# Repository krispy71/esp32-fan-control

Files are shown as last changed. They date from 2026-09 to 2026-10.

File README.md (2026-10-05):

# esp32-fan-control

Smart temperature and airflow controller for charcoal and wood-based smokers built on the ESP32 microcontroller.

## Overview

The controller continuously reads temperature sensors in the smoke chamber and meat, orchestrating both a **5V forced-air blower fan** and a **servo-controlled mechanical damper** (inspired by the **HeaterMeter** and **Roto-Damper** / **MicroDamper** open-hardware projects).

### Key Features

* **Dual-Actuator Airflow Management**:
  * **Servo-Controlled Damper**: Prevents the convective "chimney draft effect" when the pit reaches target temperature, and provides fine-tuned natural draft regulation at low-and-slow cooking temperatures ($225^\circ\text{F}$).
  * **5V Radial Blower Fan**: Kicks in automatically above a configurable airflow threshold to deliver forced air during warm-up, setpoint recovery, or high-heat cooks.
  * **RJ45 Interface**: Uses the 8P8C pin assignments (Pins 3: +5V, 4: GND, 5: +5V Fan, 6: Servo Signal) with 5V damper/fan hardware. This project's USB power rail is 5V.
* **Multi-Probe Temperature Acquisition**:
  * Supports one K-type pit probe through a MAX31855K by default, or a MAX31856 K-type build; a second wired food converter is optional.
  * Supports wireless temperature probes (e.g. MEATER / BLE beacons) behind a pluggable sensor interface.
* **Autonomous Safety & Fail-Safes**:
  * All closed-loop regulation and safety logic reside strictly on the ESP32.
  * **Lid-Open Detection**: Detects rapid negative $\Delta T$ and automatically halts the fan and closes the damper to prevent firebox flare-ups.
  * **Fail-Safe Shutdown**: Automatically closes damper and stops fan on sensor disconnect.
* **Local Web Control Interface**:
  * Reachable over local Wi-Fi using provisioned HTTPS access to monitor graphs, adjust setpoints, and tune PID/servo calibration parameters without requiring cloud services.

## Documentation

* [Project North Star](docs/north-star.md) — System requirements, behavior, and acceptance criteria.
* [System Architecture & Engineering Specification](docs/system-architecture.md) — Electrical schematic, pinout, circuit design, and modulation curves.
* [PocketSWE Agent Contract](AGENTS.md) — Onion architecture invariants and dependency rules.
* [Firmware setup and testing](firmware/README.md) — Converter selection, build commands, and physical bench checklist.
* [Private device access](docs/device-access.md) — Per-device credentials, certificates, and simulator setup.
* [Review verification](docs/review-verification.md) — Software evidence and remaining physical qualification.

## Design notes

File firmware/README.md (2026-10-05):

# ESP32 Smoker Controller Firmware & Web Interface

Embedded C++17 firmware and offline-first web dashboard for the ESP32 Smoker Fan & Servo Damper Controller, structured using the PocketSWE Onion Architecture.

---

## 1. Directory Structure

```text
firmware/
├── platformio.ini              # PlatformIO build configuration (esp32dev / esp32dev-max31856 / native)
├── partitions.csv              # Custom 4MB partition table (2.5MB App + 1.44MB LittleFS)
├── include/                    # Common project headers
├── data/                       # LittleFS web dashboard static assets
│   ├── index.html              # Responsive pitmaster control dashboard
│   ├── style.css               # Dark theme responsive mobile-first stylesheet
│   └── app.js                  # Authenticated polling telemetry client & HTML5 canvas trend graph
├── src/
│   ├── Domain/                 # Pure domain business logic (zero Arduino/ESP32 dependencies)
│   │   ├── Temperature.hpp     # TemperatureReading, SensorRole, SensorFault
│   │   ├── Airflow.hpp         # AirflowDemand, ActuatorTargets, ActuatorCoordinator
│   │   ├── Configuration.hpp   # SmokerConfig domain model and validation invariants
│   │   ├── PID.hpp             # Discrete PID regulator with anti-windup clamping
│   │   ├── LidDetector.hpp     # Lid-open suppression state machine
│   │   └── BLEDecoder.hpp      # Passive advertisement packet decoders (MEATER, Inkbird)
│   ├── Services/               # Core application orchestration
│   │   ├── Ports/              # Abstract hardware contracts
│   │   │   ├── TemperatureSensorPort.hpp
│   │   │   ├── DamperActuatorPort.hpp
│   │   │   ├── BlowerActuatorPort.hpp
│   │   │   ├── ConfigStoragePort.hpp
│   │   │   └── TelemetryPort.hpp
│   │   └── SmokerControlService.hpp
│   ├── Adapters/               # Concrete hardware, network, and storage drivers
│   │   ├── Actuators/
│   │   │   ├── ESP32ServoDamperAdapter.hpp # 50Hz LEDC PWM with idle-detach
│   │   │   └── ESP32PWMBlowerAdapter.hpp   # 25kHz ultrasonic MOSFET PWM
│   │   ├── Sensors/
│   │   │   ├── MAX31855SensorAdapter.hpp   # SPI thermocouple acquisition & fault decoding
│   │   │   ├── BLEProbeAdapter.hpp         # BLE passive scanner for meat probes
│   │   │   └── CompositeSensorAdapter.hpp  # Wireless primary with wired thermocouple fallback
│   │   ├── Telemetry/
│   │   │   └── SerialTelemetryAdapter.hpp  # Console/serial output formatter
│   │   ├── Storage/
│   │   │   └── ESP32NVSConfigAdapter.hpp   # Non-Volatile Storage (NVS) Preferences adapter
│   │   └── Network/
│   │       └── WebServerAdapter.hpp        # HTTPS REST endpoints & LittleFS allowlist
│   └── Controller/
│       └── main.cpp            # FreeRTOS task setup & pin bootstrap
└── test/
    └── test_domain.cpp         # Host-executable C++17 unit tests
```

---

## 2. Hardware Pinout Reference

> For complete point-to-point breadboard wiring and schematics, refer to [docs/wiring-diagram.md](../docs/wiring-diagram.md).

| Function | ESP32 GPIO | Peripheral / Mode | Notes |
| :--- | :---: | :--- | :--- |
| **Blower Fan Gate** | `GPIO 25` | LEDC Ch 0, 25 kHz PWM | Drives gate of N-MOSFET (AO3400A / IRLZ44N) |
| **Servo Damper Signal** | `GPIO 26` | LEDC Ch 2, 50 Hz PWM | Connects to RJ45 Pin 6 (MG90S micro-servo) |
| **SPI SCK** | `GPIO 18` | Hardware SPI Clock | Shared clock line for MAX31855 amplifiers |
| **SPI MISO** | `GPIO 19` | Hardware SPI Data | Shared serial data in from MAX31855 |
| **CS Pit Thermocouple** | `GPIO 5` | Active-low Chip Select | Dedicated CS for pit/chamber probe |
| **SPI MOSI** | `GPIO 23` | Hardware SPI Data | Required for display and MAX31856 |
| **CS Food Thermocouple** | `GPIO 21` | Active-low Chip Select | Optional; disabled unless `SMOKER_FOOD_CS=21` |

---

## 3. Web Dashboard & REST API Endpoints

The web dashboard is served over HTTPS from ESP32 LittleFS using a per-device SoftAP and administrator credential. Provision the private access files using [docs/device-access.md](../docs/device-access.md). Unprovisioned firmware keeps web access disabled while wired control remains autonomous.

### HTTP Endpoints

| Method | Endpoint | Description |
| :--- | :--- | :--- |
| `GET` | `/` | Serves dashboard HTML (`index.html`) |
| `GET` | `/style.css` | Serves dark theme CSS |
| `GET` | `/app.js` | Serves real-time JavaScript frontend |
| `GET` | `/api/telemetry` | Returns instantaneous JSON state snapshot |
| `GET` | `/api/command?id=...` | Poll queued/applied/rejected command and persistence result |
| `GET` | `/api/config` | Read active tuning, calibration, and configuration version; cloud token redacted |
| `POST` | `/api/setpoint` | Update pit setpoint: `{"setpoint": 225.0, "config_version": 0}` |
| `POST` | `/api/config` | Update tuning parameters and persist to NVS flash |
| `POST` | `/api/lid-pause` | `{"action":"pause","config_version":0}` or `"resume"` |

All routes require administrator authentication over TLS. The dashboard polls telemetry
at 1 Hz. Each POST requires the current `config_version` returned by `/api/config`;
stale versions return 409. A 202 response contains a `request_id`, indicating queued
acceptance. Poll `/api/command?id=...` until applied/rejected and check `persistence`:
`saved`, `failed`, `unchanged`, or `not_configured`. An applied setting can still fail to
persist; the dashboard reports this separately. A pending command prevents a second
submission until its result is collected. The last eight results are retained in RAM.

`POST /api/config` accepts tuning and calibration fields, including
`servo_min_pulse_us`, `servo_max_pulse_us`, and `servo_inverted`. Omit
`meater_cloud_token` to preserve it; send an empty string to remove it. API responses
expose only whether it is configured.

### Example Telemetry JSON Payload

```json
{
  "timestamp_ms": 142300,
  "pit_temp_f": 224.8,
  "meat_temp_f": 165.2,
  "setpoint_f": 225.0,
  "damper_position_pct": 42.0,
  "blower_speed_pct": 0.0,
  "demand_pct": 17.0,
  "is_pit_valid": true,
  "is_meat_valid": true,
  "lid_open": false,
  "status": "REGULATING",
  "is_meat_wireless": true,
  "meat_battery_pct": 92,
  "meat_probe_name": "MEATER+"
}
```

---

## 4. FreeRTOS Task Architecture

* **Core 1 — Control task (`SmokerControl`)**, priority 2: owns the control service,
  actuator state, and wired sensor sampling. It runs PID and normal telemetry at a nominal 1 Hz, checks pit safety between
  those cycles, and services converter/servo upkeep every 20 ms. Hardware transactions and task scheduling add
  latency; physical timing must be measured on the bench.
* **Core 0 — Network task (`SmokerNetwork`) and HTTPS server**: updates BLE/cloud
  caches, serves the dashboard, and renders the display. Web requests submit typed
  commands through a bounded queue and read copied state; they never mutate the
  control service directly. Wireless cache exchanges use short locks.

The pinned Arduino 2.0.17 BLE client has service-discovery ownership defects.
`tools/patch_ble_client.py` uses a [PlatformIO build middleware](https://docs.platformio.org/en/latest/scripting/middlewares.html)
to compile a repaired copy under `.pio/build/<environment>/patched_ble`:
duplicate service UUID instances are discarded before allocation, and rediscovery
clears the secondary service index. The shared framework installation is unchanged.
An unexpected source checksum stops the build so framework upgrades require an
explicit patch review. `test/test_ble_sdk_patch.py` executes the emitted vendor
discovery and cleanup bodies across repeated duplicate-instance discoveries.
* **Shared SPI**: an explicit bus owner serializes complete display/converter frames,
  including transaction settings and chip-select lifetime. The display uses MOSI23.
* **Startup**: application ownership is constructed inside `setup()`. The blower is
  stopped, saved configuration is loaded, calibrated closure is commanded, and then
  tasks start. LEDC fan channel 0 and servo channel 2 use independent timers.

---

## 5. Building, Testing, and Simulation

### Repeatable software verification

From the repository root, install `uv`, a C++17 compiler, OpenSSL, Node/npm (for browser accessibility checks), and the runtime
libraries `libcjson.so.1` and `libmbedcrypto.so.7`. Build an ESP32 environment once to
install its framework headers, then run:

```bash
uv run --no-project --with platformio pio run -d firmware -e esp32dev
uv run --no-project --with playwright==1.58.0 python -m playwright install chromium
tools/verify.sh --firmware --browser
```

The driver runs Python tests, strict C++ domain/service/native checks, production
Arduino paths against SPI/PWM/NVS spies, the firmware HTTPS handler, both ESP32
converter builds, and the real simulator/browser flow. Omit `--firmware` or
`--browser` to skip those optional stages. Hardware spies do not establish electrical
accuracy or actual servo movement.

### Running Local Python Web Simulation
Launch the desktop simulator with the live web dashboard served at `https://127.0.0.1:8443`:

```bash
uv run python -m esp32_fan_control.Controller.cli --web --access-dir "$HOME/.local/share/esp32-smoker/device-a"
```

### Compiling Firmware for ESP32 Target
Using PlatformIO Core via `uv`:

```bash
cd firmware
uv run --with platformio pio run -e esp32dev
```

The default `esp32dev` environment supports one wired **K-type probe through a
MAX31855K** on CS5. For a MAX31856 configured as K-type, build
`-e esp32dev-max31856` and connect MOSI23 as well. A second wired food converter is
optional: add `-D SMOKER_FOOD_CS=21` to that environment's build flags when installed.
Both converters share SCK18/MISO19 and have separate CS pins. Never connect a bare
thermocouple directly to an ESP32 analog input.

### Flashing Firmware & LittleFS Web Assets to ESP32

First provision and copy the three private device files described in
[device access](../docs/device-access.md). Substitute the MAX31856 environment in
both upload commands when using that converter.
```bash
cd firmware

# 1. Upload program binary (compiled against custom 2.5MB app partition)
uv run --with platformio pio run -e esp32dev -t upload

# 2. Upload web dashboard files from firmware/data/ to LittleFS partition (1.44MB)
uv run --with platformio pio run -e esp32dev -t uploadfs

# 3. Open interactive serial console with automatic exception decoder
uv run --with platformio pio device monitor -b 115200
```

---

## 6. Hardware Flashing & Pre-Flight Verification Checklist

Before connecting high-draw actuators or attaching the unit to your smoker, complete this pre-flight verification sequence on the bench.

### 6.1 Pre-Power Multimeter & Pin Sanity Check

Perform these checks with the ESP32 **unpowered**:

- [ ] **Power Rail Isolation**: Check resistance between the 5V rail and GND using a multimeter. Ensure no short circuit exists ($R > 10\,\text{k}\Omega$).
- [ ] **Logic Level Isolation (3.3V vs 5V)**:
  - Verify MAX31855 VCC is wired strictly to ESP32 `3V3` (3.3V LDO pin), **never** to 5V.
  - Verify Blower Fan (+) and Servo (+) are connected to the 5V USB rail.
- [ ] **Flyback Diode Orientation**: Ensure the 1N5819 diode is placed directly across the fan terminals with the **cathode (silver band)** connected to +5V and **anode** connected to the MOSFET Drain (Fan -).
- [ ] **Gate Pull-Down**: Verify the $100\,\text{k}\Omega$ resistor is connected between `GPIO 25` (MOSFET Gate) and `GND`. This guarantees the blower fan remains completely off when the ESP32 is booting or in reset.
- [ ] **Brownout Buffer Capacitor**: Confirm the $1000\,\mu\text{F}$ electrolytic capacitor across the 5V bus is installed with correct polarity (negative stripe to GND).

### 6.2 Flashing & Initial Boot Verification

1. Connect the ESP32 DevKit to your computer via USB.
2. Flash the firmware binary and LittleFS filesystem:
   ```bash
   cd firmware
   uv run --with platformio pio run -e esp32dev -t upload
   uv run --with platformio pio run -e esp32dev -t uploadfs
   ```
3. Open the serial terminal:
   ```bash
   uv run --with platformio pio device monitor -b 115200
   ```
4. Verify startup behavior:
   - [ ] Fan remains off until a valid pit sample is available; servo closes at boot.
   - [ ] With provisioned access files, serial reports
     `[Web] Provisioned HTTPS dashboard ready on port 443.`
   - [ ] The private per-device SSID becomes visible; no password is printed.
   - [ ] No shared-bus or control-task initialization error is reported.
   - [ ] Periodic telemetry shows pit validity, demand, damper, fan, and lid status.

### 6.3 Functional Bench Calibration & Verification

Step through each subsystem to confirm physical hardware operation:

#### A. Thermocouple Subsystem (MAX31855K or MAX31856)
- [ ] **Ambient Sanity**: With thermocouple attached, verify serial console reports room temperature (~68°F – 74°F).
- [ ] **Thermal Response**: Pinch the tip of the thermocouple between your fingers; confirm temperature immediately rises to 80°F–88°F.
- [ ] **Open-Circuit Fault Detection**: Unplug or disconnect one thermocouple lead. Verify the serial log reports a pit fault and demand drops to `0.0%` (failsafe lock).

#### B. Damper Actuator Subsystem (MG90S Servo)
- [ ] **Zero-Position (Closed)**: At initial boot, confirm the damper rotor moves to fully closed position ($0^\circ$).
- [ ] **Idle-Detach Verification**: Observe the servo after it reaches position. Within 1.5 seconds, the ESP32 automatically detaches the PWM pin (`ledcDetachPin`). Confirm all servo hum, vibration, and jitter stops completely.
- [ ] **Full Range Sweep**: Adjust calibration in the dashboard and verify closed/open mechanical endpoints and direction. Confirm values persist across a reboot; verify movement is followed by idle detach.

#### C. Blower Fan Subsystem (N-MOSFET & 25kHz PWM)
- [ ] **Low-Demand Deadband**: When demand is below the airflow threshold (default $\le 40\%$), confirm the blower fan is completely idle (0% duty cycle) while the damper modulates airflow.
- [ ] **High-Demand Activation**: When demand exceeds the configured threshold (default 40%), confirm the blower fan spins up smoothly without any audible coil whine (verified 25 kHz ultrasonic PWM).
- [ ] **Max Speed (100% Demand)**: At 100% demand, confirm the fan runs at full 5V velocity.

#### D. Web Dashboard & Wi-Fi Connectivity
- [ ] Connect to the per-device Wi-Fi network listed in your private `operator-access.txt`.
- [ ] Open a browser and navigate to `https://192.168.4.1`.
- [ ] Verify the responsive pitmaster dashboard loads with real-time temperature gauges and canvas graph.
- [ ] Tap the **Setpoint** control, enter `250`, and submit. Verify:
  - Web UI displays new setpoint.
  - Dashboard reports application and successful persistence.
  - The value persists after power-cycling the ESP32 (stored in NVS flash).
- [ ] Tap **Lid Open Pause**. Verify status changes to `LID_OPEN`, blower turns off, and damper closes. Use the resume control to cancel.

#### E. Wireless BLE Meat Probe Verification (Optional / If Equipped)
- [ ] Turn on a compatible BLE meat probe (MEATER, Inkbird, or BBQ-BT).
- [ ] Within 10–30 seconds, confirm the serial log and web dashboard update the meat channel from `N/C` to the live wireless temperature reading with probe name and battery status (e.g. `Meat: 135.2 F [MEATER+ 95%]`).
- [ ] If a wired thermocouple is also plugged into the Food 1 channel, remove the wireless probe or move it out of range; verify the controller cleanly falls back to the wired probe reading without interrupting the pit regulation loop.

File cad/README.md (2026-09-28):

# Parametric Fan & Servo Damper CAD

This directory contains the 3D-printable mechanical CAD design for the ESP32 Smoker Controller, implemented in OpenSCAD.

> **Mechanical Guides**:
> - **Design 1 (Integrated Barrel Damper Pod)**: See [docs/assembly-guide.md](../docs/assembly-guide.md) and [docs/3d-printed-parts-guide.md](../docs/3d-printed-parts-guide.md).
> - **Design 2 (Roto-Damper RD3 Rotary Puck)**: See [docs/roto-damper-guide.md](../docs/roto-damper-guide.md).

| Design 1: Integrated Barrel Damper Pod | Design 2: Roto-Damper RD3 Rotary Puck |
| :---: | :---: |
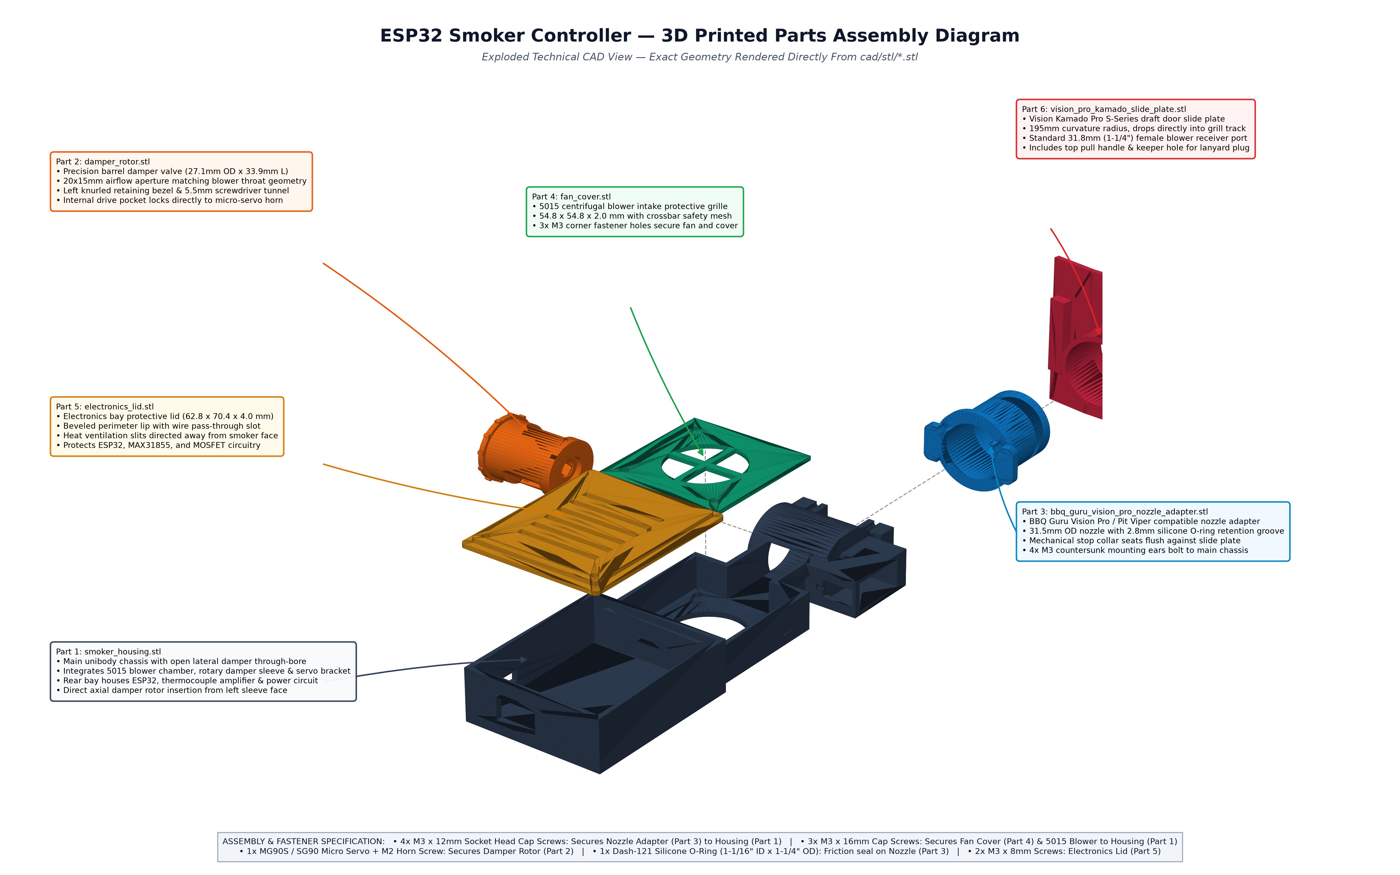
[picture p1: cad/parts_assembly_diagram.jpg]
Design 1 Exploded Diagram
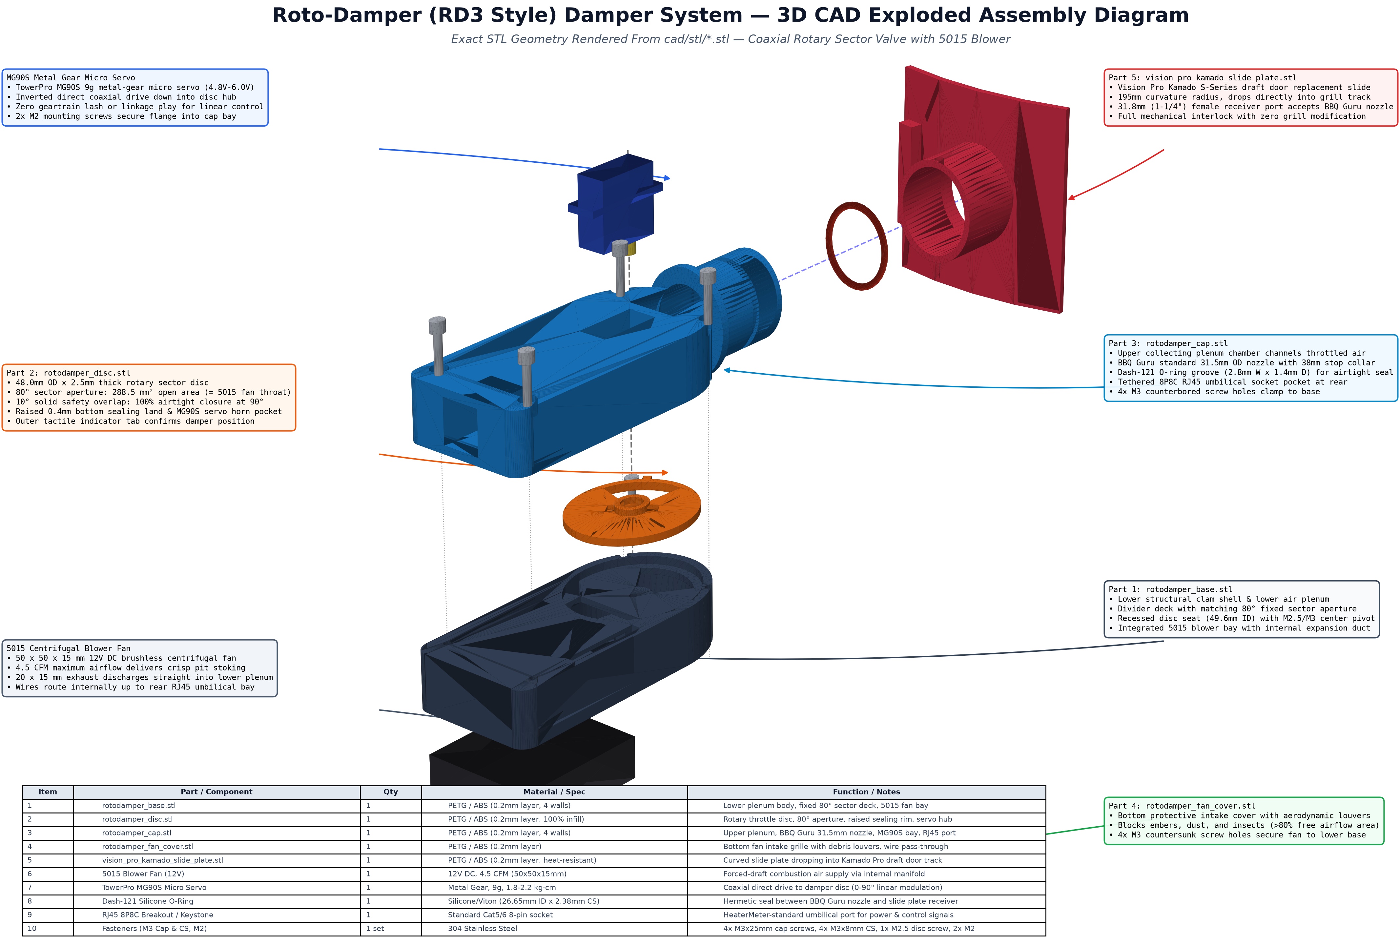
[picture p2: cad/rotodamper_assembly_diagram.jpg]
Design 2 Exploded Diagram
|  |  |

---

## Design Highlights

1. **Parametric Output Adapter**:
   - **BBQ Guru Vision Pro / Pit Viper Preset** (`output_preset = "bbq_guru"`):
     - Sized specifically to fit into the BBQ Guru metal Vision Pro S-Series adapter sleeve (`https://www.bbqguru.com/product/vision-pro-adapter-s-series/`).
     - Outer diameter: **31.5mm** (standard 1-1/4" nominal with 0.25mm slip-fit clearance).
     - Insertion length: **32.0mm** with 1.5mm lead-in chamfer.
     - Integrated O-ring retention groove (2.8mm wide, 1.4mm deep, located 10mm from tip) for airtight friction sealing with standard Dash-121 / Dash-122 silicone O-rings.
     - Integrated 38mm mechanical stop collar to prevent over-insertion against the adapter face.
   - **Vision Pro S-Series Curved Slide Door Replacement** (`part = "vision_pro_plate"`):
     - Complete 3D-printable curved slide door that drops directly into the Vision Kamado Pro S-Series bottom vent track (width: 82mm, height: 74mm, radius: 195mm).
     - Features a female 31.8mm BBQ Guru receiver port and pull handle tab.
   - **Round Pipe**: Configurable outer diameter (e.g., 25.4mm for 1" NPT, 31.75mm for 1.25", or 38.1mm for 1.5").
   - **Rectangular Duct**: Configurable width and height to match Kamado bottom slide vents (Big Green Egg, Kamado Joe) or Weber Smokey Mountain (WSM) draft dampers.
   - **Mounting Flange**: Optional bolt-on flange with configurable screw spacing.
   - **Modular Attachment**: The output nozzle attaches via 4x M3 screws, allowing you to swap smoker adapters without reprinting the main housing.

2. **Parametric Fan Sizing**:
   - `fan_size` & `fan_depth` accommodate standard radial blower sizes:
     - **5015** (`fan_size = 50`, `fan_depth = 15`): Ultra-compact for small/medium cookers (WSM 18.5", Kamado Classic).
     - **7530** (`fan_size = 75`, `fan_depth = 30`): High-output for drum smokers and larger pits.
     - **9733** (`fan_size = 97`, `fan_depth = 33`): Heavy-duty commercial/offset airflow.

3. **Two System Packaging Configurations**:
   - **Configuration A: All-in-One Integrated Pod (`include_electronics_bay = true`)**:
     - Contains an attached electronics bay housing the ESP32 development board, 5V USB-C power breakout, MOSFET blower switch, and MAX31855 thermocouple amplifier.
     - Direct USB-C power connection for phone chargers and USB battery bricks.
   - **Configuration B: Slim Tethered Pod (`include_electronics_bay = false`)**:
     - Eliminates the electronics bay in favor of an RJ45 modular jack recess.
     - Connects via standard Cat5/Cat6 umbilical cable to a remote controller base unit.

4. **Servo-Driven Damper Valve**:
   - Houses a TowerPro MG90S metal-gear (or SG90) micro-servo.
   - The cylindrical barrel rotor features a cross-bore aperture that aligns with the fan exhaust at 90° rotation and hermetically blocks the airway at 0° to prevent the chimney draft effect.

---

## Printable Parts in `smoker_damper.scad`

Select which component to render via the `part` variable or from the command line:

```bash
# 1. Main Housing Body (holds fan, damper, and servo)
openscad -o housing.stl -D 'part="housing"' smoker_damper.scad

# 2. Damper Rotor (rotating valve cylinder)
openscad -o rotor.stl -D 'part="rotor"' smoker_damper.scad

# 3. Output Adapter - BBQ Guru Vision Pro / Pit Viper Nozzle (1.25" / 31.5mm OD with O-ring groove)
openscad -o adapter_bbq_guru.stl -D 'part="output_adapter"; output_preset="bbq_guru"' smoker_damper.scad

# 4. Vision Pro S-Series Curved Slide Door Replacement Plate (drops into Kamado track)
openscad -o vision_pro_plate.stl -D 'part="vision_pro_plate"' smoker_damper.scad

# 5. Output Adapter - Round Pipe (1" NPT)
openscad -o adapter_round.stl -D 'part="output_adapter"; output_preset="npt_1"' smoker_damper.scad

# 6. Output Adapter - Rectangular (50mm x 30mm)
openscad -o adapter_rect.stl -D 'part="output_adapter"; output_preset="kamado_rect"' smoker_damper.scad

# 7. Electronics Bay Lid (for Config A)
openscad -o lid.stl -D 'part="lid"' smoker_damper.scad

# 8. Fan Intake Protective Grille
openscad -o fan_cover.stl -D 'part="fan_cover"' smoker_damper.scad
```

---

## Printable Parts in `roto_damper.scad` (Design 2: Roto-Damper)

Compile the modular 4-piece Roto-Damper puck:

```bash
# 1. Base Housing (lower shell, 5015 fan bay, static lower plenum, sector deck)
openscad -o rotodamper_base.stl -D 'part="base"' roto_damper.scad

# 2. Rotary Damper Disc (80-degree sector aperture, low-friction rim, servo hub)
openscad -o rotodamper_disc.stl -D 'part="disc"' roto_damper.scad

# 3. Cap Housing (upper plenum, 31.5mm BBQ Guru nozzle, MG90S bay, RJ45 port)
openscad -o rotodamper_cap.stl -D 'part="cap"' roto_damper.scad

# 4. Fan Cover (bottom intake grille with aerodynamic louvers)
openscad -o rotodamper_fan_cover.stl -D 'part="fan_cover"' roto_damper.scad
```

Pre-compiled binary STL files ready for slicing are available in `cad/stl/`.

---

## Assembly Diagram Generation

The technical exploded assembly diagrams (`parts_assembly_diagram.jpg` and `rotodamper_assembly_diagram.jpg`) are generated directly from the 3D meshes in `cad/stl/`:

```bash
# Design 1 (Barrel Damper Pod) Assembly Diagram:
uv run --with numpy-stl --with matplotlib --with pillow python cad/render_assembly_diagram.py

# Design 2 (Roto-Damper RD3 Rotary Puck) Assembly Diagram:
uv run --with numpy-stl --with matplotlib --with pillow python cad/render_rotodamper_assembly.py
```

---

## 3D Printing Recommendations

* **Material**: **PETG**, **ABS**, or **ASA** are strongly recommended. PLA is **not** recommended due to radiant heat near smoker firebox vents ($>60^\circ\text{C}$).
* **Layer Height**: $0.20\,\text{mm}$ (or $0.16\,\text{mm}$ for the rotor to ensure smooth surface finish).
* **Infill**: $25\%\text{--}40\%$ gyroid or grid for structural rigidity.
* **Perimeters/Walls**: 4 perimeters for heat resistance and air-tightness.
* **Rotor Fit**: The default clearance is $0.45\,\text{mm}$. If the rotor fits too tightly in the housing, adjust `rotor_clearance = 0.55` before slicing. A small touch of food-safe silicone lubricant or graphite can be applied to the barrel for zero-friction movement.
* **BBQ Guru O-Ring**: Use a standard Dash-121 (1-1/16" ID x 1-1/4" OD x 3/32" C/S) or Dash-122 (1-1/8" ID) high-temperature red silicone O-ring in the nozzle groove.

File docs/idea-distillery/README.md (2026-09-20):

# Idea Distillery analysis

Run `esp32-fan-control-d7a12df-r2` analyzed this project's README at commit
`d7a12df` using the Codex CLI provider and `gpt-6-astra`.

- [Recommendations](esp32-fan-control-d7a12df-r2/recommendations.md)
- [Ideate Engine seeds](esp32-fan-control-d7a12df-r2/ideate-seeds.md)
- [Structured recommendations](esp32-fan-control-d7a12df-r2/recommendations.json)
- [Provenance and export manifest](esp32-fan-control-d7a12df-r2/manifest.json)

All eight persona assessments succeeded across two themes. The result contains
one in-repository proposal, three standalone or integration proposals, two
non-goals, and four project seeds.

The leading in-repository recommendation is to build a wired-probe fan-control
loop first, then add independently validated wireless sensor adapters.
Confidence is low: the evidence describes product intent without implementation
or validation results. Wireless-probe APIs and commercial demand remain unverified.

The local control-interface proposal was classified as a non-goal after its
repository host candidate was rejected. Review that classification before using
the generated matrix as an implementation plan.

These are the exact canonical exports. Their historical replay and all four
source references were verified before publication. Local filesystem paths in
the exports record the original environment; the corresponding source is
[`README.md` at `d7a12df`](https://github.com/krispy71/esp32-fan-control/blob/d7a12df/README.md).

An initial run exposed a Codex migration-track parser bug. The successful run
used the corrected adapter; the fix and regression coverage are included in
[Idea Distillery commit `ec88c1c`](https://github.com/krispy71/idea-distillery/commit/ec88c1c).

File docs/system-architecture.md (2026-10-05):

# ESP32 Smoker Fan & Servo Damper Controller — System Architecture & Engineering Specification

> Comprehensive architectural breakdown and hardware/firmware specification for the ESP32-based Smoker Controller.

---

## 1. Hardware & Electrical Architecture

> See the full point-to-point pinout guide and schematic in [docs/wiring-diagram.md](wiring-diagram.md).

The system is designed around a single **5V DC power bus** sourced via USB-C or micro-USB, allowing direct operation from standard USB wall chargers ($5\text{V }2.0\text{A}\text{--}3.0\text{A}$) and portable USB power banks/battery bricks.

```text
                               +-----------------------------+
                               |     5V DC Power Input       |
                               |  (USB-C / USB Power Bank)   |
                               +--------------+--------------+
                                              |
                       +----------------------+----------------------+
                       |                                             |
                       v                                             v
       +-------------------------------+             +-------------------------------+
       |       5V Blower Rail          |             |     5V Servo & Logic Rail     |
       |  (Direct or via RJ45 Pin 5)   |             |    + LC Filter & 1000uF Cap   |
       +---------------+---------------+             +---------------+---------------+
                       |                                             |
                       |                             +---------------+---------------+
                       |                             |                               |
                       v                             v                               v
         +---------------------------+  +-------------------------+    +---------------------------+
         | Low-Side N-MOSFET Switch  |  |   5V Micro-Servo Rail   |    |    ESP32 Onboard LDO      |
         | (AO3400A / IRLZ44N)       |  |  (MG90S / SG90)         |    |     (5V -> 3.3V Rail)     |
         | + Flyback Diode (1N5819)  |  |   (Direct or RJ45 P3)   |    +-------------+-------------+
         +-------------^-------------+  +-------------------------+                  |
                       |                                                             v
                       | PWM Fan Gate (LEDC)                           +---------------------------+
                       |                                               |     ESP32 Dual-Core       |
                       +-----------------------------------------------+ GPIOs (3.3V Logic)       |
                                                                       |                           |
                                      50Hz Servo PWM Signal (LEDC)     | • Core 0: Wi-Fi / Web     |
                                  +------------------------------------+ • Core 1: Control Loop    |
                                  |                                    +-------------+-------------+
                                  v                                                  |
                     +--------------------------+                                    | SPI Bus
                     | 3.3V -> 5V Level Buffer  |                                    v
                     | (74AHCT1G125 or FET)     |                      +---------------------------+
                     +--------------------------+                      | Thermocouple ICs          |
                                                                       | (MAX31855 / MAX31856)     |
                                                                       +---------------------------+
```

### 1.1 Physical Packaging Configurations

The system supports two physical deployment models:

#### Configuration A (Primary — All-in-One Integrated Pod)
* **Description**: The 3D-printed housing holds the blower fan, servo damper, ESP32 microcontroller development board, thermocouple amplifier, and 5V USB-C power breakout in a single compact enclosure mounted directly to the smoker inlet vent.
* **Benefits**: Zero umbilical cables running between boxes; completely self-contained. The user connects only a USB-C power cable from a battery brick and thermocouple probe leads.
* **CAD Implementation**: OpenSCAD model `cad/smoker_damper.scad` with `include_electronics_bay = true`. Features internal cable raceways, USB-C socket cutout, thermocouple socket opening, and ventilated lid.

#### Configuration B (Secondary — Modular / Tethered Base Unit)
* **Description**: A remote base station (placed safely on a prep table) houses the ESP32, display, and probe inputs, connecting to a slim damper/fan head mounted on the smoker via an RJ45 umbilical cable.
* **Benefits**: Keeps the microcontroller, display, and electronics further away from smoker radiant heat and grease.
* **Interface**: Standard 8P8C (RJ45) jack conforming to the HeaterMeter community standard (standard T568B Cat5/Cat6 cabling):

| RJ45 Pin | T568B Wire Color | Function | Description |
| :---: | :---: | :---: | :--- |
| **1** | White / Orange | NC | Reserved / Unused |
| **2** | Orange | NC | Reserved / Unused |
| **3** | White / Green | **+5V Servo Power** | Regulated 5V rail for RC micro-servo |
| **4** | Blue | **Common Ground** | Shared ground for 5V Blower and 5V Servo |
| **5** | White / Blue | **+5V Blower Power** | Switched 5V rail for blower fan (or constant 5V with switched return) |
| **6** | Green | **Servo Signal** | 50Hz PWM control signal (5V buffered logic) |
| **7** | White / Brown | NC | Reserved / Unused |
| **8** | Brown | NC | Reserved / Unused |

### 1.2 Blower Fan Driver Circuit
* **Actuator**: 5V DC radial blower (e.g. 5015, 7530, or 9733 5V radial blower, typical current $0.2\text{A}\text{--}0.7\text{A}$).
* **Switching Element**: Low-side N-channel logic-level MOSFET (e.g. AO3400A or IRLZ44N) with low $R_{DS(\text{on})} < 0.03\,\Omega$ at $V_{GS} = 3.3\text{V}$.
* **Gate Drive**: Driven from an ESP32 LEDC PWM GPIO with a $150\,\Omega$ gate damping resistor and a $100\,\text{k}\Omega$ pull-down resistor to ground (holds gate LOW during boot/reset).
* **Snubber / Flyback**: 1N5819 Schottky diode across the blower terminals to absorb inductive flyback pulses during high-frequency PWM switching.

### 1.3 Servo Damper Driver Circuit
* **Actuator**: Micro-servo (TowerPro MG90S metal-gear or SG90).
* **Power & Filtering**: Powered directly by the 5V bus. Because micro-servos can draw stall current pulses upwards of $800\,\text{mA}$, a dedicated $1000\,\mu\text{F}$ low-ESR electrolytic capacitor and a $0.1\,\mu\text{F}$ ceramic capacitor are placed right at the servo power connection to prevent brownout glitches on the ESP32.
* **Signal Buffering**: 50Hz PWM pulse signal generated by ESP32 LEDC peripheral (500µs–2500µs pulse width) is buffered to 5V logic via a 74AHCT1G125 or small N-FET buffer to ensure clean edge transitions over longer cable runs.

### 1.4 Parametric OpenSCAD Mechanical Housing
The mechanical CAD design (`cad/smoker_damper.scad`) is fully parametric:
* **Fan Geometry**: Accommodates any blower form factor (`fan_size` 50mm, 75mm, 97mm; `fan_depth` 15mm, 30mm, 33mm).
* **Smoker Interface**: Modular nozzle adapter with both **round** (e.g. 1" or 1.25" NPT pipe) and **rectangular** (e.g. 50mm x 30mm sliding door) duct options and configurable mounting flange.
* **Electronics Enclosure**: Toggleable integrated electronics bay (Config A) vs slim RJ45 connector block (Config B).

---

## 2. Airflow Coordination & Control Theory

Smoker fires operate on fuel-rich combustion: the temperature is governed almost entirely by available oxygen.

```text
              Airflow Modulation Profile (Sequential / Dual-Stage)
              
    100% |                                      /----------------- Damper Position (100%)
         |                                     /
  Actuator|                                   /                  / Blower Speed (0 -> 100%)
  Output |                                  /                 /
         |                                 /                /
         |                                /               /
         |                               /              /
      0% |------------------------------+-------------+
         0%                       Threshold (e.g. 40%)      100%
                               Total Airflow Demand (PID Output)
```

### 2.1 The Chimney Effect & Damper Elimination
When a smoker is hot, hot air rising up through the exhaust stack creates a strong natural vacuum (the chimney effect). With a standard blower fan, this vacuum pulls fresh air directly through the stationary fan blades, causing the coals to stoke uncontrollably even with the fan at 0%.
- **Solution**: At $0\%$ demand, the servo closes the physical damper shutter to $0^\circ$ aperture, hermetically sealing the intake and stopping thermal runaway.

### 2.2 Dual-Stage Modulation ("On Above" Mode)
The PID algorithm outputs an abstract demand from $0.0$ to $1.0$ ($0\text{--}100\%$):
1. **Stage 1 — Natural Draft Regulation ($0\% < \text{Demand} \le \text{Threshold}$)**:
   - For typical low-and-slow cooks ($225^\circ\text{F}\text{--}250^\circ\text{F}$), forced air from a blower is often too aggressive, kicking up ash and overshooting target temps.
   - The damper aperture scales linearly from $0\%$ to $100\%$ while the **blower fan remains completely OFF**. Natural convective draft smoothly feeds the fire.
2. **Stage 2 — Forced Draft Boost ($\text{Demand} > \text{Threshold}$)**:
   - The damper remains locked at $100\%$ fully open.
   - The blower fan engages at its minimum speed and scales linearly up to $100\%$ duty cycle, providing forced air when large heat additions are required (e.g., startup, lid recovery, or high-heat grilling).

### 2.3 Servo Idle Detach
Holding a hobby servo at a stationary position under continuous 50Hz PWM pulses causes servo jitter, hum, and unnecessary power consumption.
- The firmware provides an auto-detach feature: once the servo reaches its target position, PWM pulses are disabled after 1.5 seconds of settling time. Pulses are re-enabled dynamically whenever the target position changes by $\ge 1\%$.

### 2.4 Lid-Open Suppression Algorithm
- The controller monitors the rolling rate of change of pit temperature: $\frac{dT_{\text{pit}}}{dt}$.
- If $\frac{dT_{\text{pit}}}{dt} < -\text{DropThreshold}$ (e.g., drops $>15^\circ\text{F}$ in under 30 seconds), the lid-open state is triggered.
- Fan is forced to $0\%$, damper is driven to $0\%$ (closed), and PID integration is paused.
- The suppression remains active for a configurable duration (default 180 seconds) or until temperature recovers, preventing the controller from blowing the firebox into an inferno while the pitmaster is spritzing or wrapping meat.

---

## 3. PocketSWE Onion Architecture Layout

The software is structured in accordance with PocketSWE and the [AGENTS.md](../AGENTS.md) contract:

```text
firmware/src/
├── Domain/       # Airflow, PID, temperature, configuration, display values,
│                 # owned telemetry and typed control commands/state
├── Services/
│   ├── SmokerControlService.hpp   # initialize, apply commands, read/control/publish
│   └── Ports/    # Sensor, damper calibration/position, blower, telemetry,
│                 # configuration storage and bounded command/state exchange
├── Adapters/
│   ├── Actuators/  # Independent fan/servo LEDC timers
│   ├── Hardware/   # Explicit shared SPI owner
│   ├── Runtime/    # Bounded command queue and copied state with short locks
│   ├── Sensors/    # MAX31855K/MAX31856, BLE/cloud caches, source selection
│   ├── Storage/    # Versioned NVS configuration record
│   ├── Telemetry/  # Serial formatting
│   ├── Display/    # E-ink driver using the shared bus
│   └── Network/    # Provisioned authenticated HTTPS and static asset allowlist
└── Controller/
    └── main.cpp    # Ownership, startup, task contexts and scheduling
```

The Python simulator under `src/esp32_fan_control` mirrors the core Domain/Services
contracts and supplies filesystem, simulated-sensor, console-actuator, bounded-channel,
and HTTPS adapters. Firmware dashboard assets live in `firmware/data` and use the
[approved embedded UI exception](ui-architecture.md).

The control task exclusively owns mutable service and actuator state. Web handlers
submit typed commands and consume owned snapshots through `IControlChannel`. A
configuration version prevents stale overwrites; command acknowledgments distinguish
application from persistence. Network tasks never call mutable service methods.

Configuration loads explicitly after Arduino startup. NVS stores one versioned record,
including servo calibration. Domain telemetry owns its strings; Domain has no Ports
imports. Concrete FreeRTOS locks and SPI transactions remain in Adapters.

One shared BLE scanner owns radio discovery and keeps only the configured direct
probe candidate. The HTTPS adapter owns two connection slots and an absolute
connection deadline covering TLS negotiation, request reads, and response writes.
These resource limits do not depend on the control task or on incoming traffic rates.

### 3.1 Inward Dependency Rules
- **Domain**: Pure business and control math. Contains no hardware timers, no ESP-IDF/Arduino includes, and no network logic. 100% testable on host/desktop environments.
- **Services**: Coordinate the domain models using Ports. Knows nothing about MOSFETs or servos—only `DamperActuatorPort` and `BlowerActuatorPort`.
- **Adapters**: Implement the ports and translate hardware nuances (e.g. converting 0-100% damper position into specific microsecond pulse timings).

---

## 4. Implementation Phasing Roadmap

- **Phase 1 — Core Dual-Actuator Firmware**:
  - Implement Domain PID and `ActuatorCoordinator` (dual-stage damper + blower logic).
  - Implement MAX31855 SPI thermocouple adapter and ESP32 LEDC servo/blower adapters.
  - Test on bench with RJ45-connected Roto-Damper / MicroDamper hardware.
- **Phase 2 — Pluggable Wireless Probe Adapters**:
  - Implement BLE scanner/client adapter for commercial wireless probes (MEATER / open BLE beacons).
  - Feed wireless readings through `TemperatureSensorPort` into the domain.
- **Phase 3 — Web Client Interface**:
  - Implement lightweight web UI (following [docs/ui-architecture.md](ui-architecture.md)) served over local Wi-Fi.
  - Expose live graphing of pit temp, meat temps, damper angle, and fan duty cycle.

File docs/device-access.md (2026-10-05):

# Private device access

The embedded dashboard uses HTTPS and a per-device administrator password. There is
no shared Wi-Fi password or default administrator password. Without valid provisioned
access files, the firmware keeps network access disabled; wired temperature control
does not require the dashboard.

## Provision a device

Install Python 3 and OpenSSL, then run from the repository root:

```bash
python3 tools/provision_device.py --output "$HOME/.local/share/esp32-smoker/device-a"
```

The command creates a private directory with files readable only by their owner:

- `device-access.json`: device SSID, Wi-Fi password, administrator password verifier,
  and allowed hostnames.
- `device-cert.pem`: the device server certificate, signed by its private device CA.
- `device-ca.pem`: the public CA certificate to trust on your clients.
- `operator-ca-key.pem`: the CA signing key; keep it off the device.
- `device-key.pem`: its private key.
- `operator-access.txt`: the operator's Wi-Fi and HTTPS credentials.

The provisioning command refuses to overwrite an existing directory and does not
print credentials. Keep `operator-access.txt` and `operator-ca-key.pem` outside the repository and device flash.
All generated access files are ignored by Git; do not force-add any access files.

Default certificate names cover `192.168.4.1`, `localhost`, and `127.0.0.1`. Use repeated
`--host` options when provisioning if different names are needed. Import `device-ca.pem`
into the trust store of each client you control before using the dashboard.
Check its fingerprint locally with:

```bash
openssl x509 -in "$HOME/.local/share/esp32-smoker/device-a/device-ca.pem" -noout -fingerprint -sha256
```

## Install on the ESP32

Copy only these files into the filesystem image:

```bash
device_dir="$HOME/.local/share/esp32-smoker/device-a"
cp "$device_dir/device-access.json" firmware/data/
cp "$device_dir/device-cert.pem" firmware/data/
cp "$device_dir/device-key.pem" firmware/data/
```

Build and upload the firmware and LittleFS image using the commands in
[firmware/README.md](../firmware/README.md). The filesystem includes private access
material, so treat its generated image as sensitive too. After upload, join the SSID
listed in the private operator file and visit `https://192.168.4.1`. The browser asks
for the administrator credentials. No credentials belong in URLs.

To rotate access, provision a new directory, replace all three device files together,
upload the new filesystem image, and trust the replacement CA certificate. Retain the
old private directory until the replacement is verified. Existing browser credentials
may need to be cleared before signing in again.

## Run the simulator

The simulator uses the same protected access directory, without copying it into the
repository:

```bash
uv run python -m esp32_fan_control.Controller.cli --web --access-dir "$HOME/.local/share/esp32-smoker/device-a"
```

Open the HTTPS URL reported by the simulator and authenticate using the private
operator file. The simulator defaults to a local loopback address.

## Configuration behavior

Control requests are authenticated and validated before entering the bounded control
queue. Acceptance into that queue is distinct from application by the control loop;
the API exposes the applied command and persistence result. Stale configuration
versions are rejected rather than silently overwriting a newer change, including after
a reboot. The controller reserves revision numbers in storage at startup. If that
reservation fails, configuration edits are rejected and reported as a storage error;
autonomous control continues. An ordinary settings-save failure is still reported
as applied but not saved.

MEATER tokens are write-only. Reading configuration reports whether a token is
configured, never its value. Leaving the token field unchanged preserves it. The
dashboard exposes explicit replacement/removal behavior. Servo calibration accepts
500–2500 microsecond limits with minimum below maximum, plus direction inversion.
The backend owns validation and applies calibration through the actuator port.

Hardware accuracy, mechanical closure, and physical fault shutdown still require the
bench procedure in [firmware/README.md](../firmware/README.md).

The shipped composition does not configure a cloud trust anchor or a station network.
MEATER cloud polling therefore stays disabled until an integrator supplies a trusted
CA certificate and internet connectivity; it never bypasses certificate validation.
Saving a cloud token alone does not enable cloud connectivity. Wired pit control and
local BLE acquisition remain independent of that optional integration.

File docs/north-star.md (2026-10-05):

# ESP32 Smoker Fan & Damper Controller — Project North Star

Created: 2026-09-27. Status: working project direction; acceptance is not yet verified.

This document defines the system outcome for the ESP32 Smoker Controller. It follows the
[PocketSWE work protocol](work-protocol.md). Stated specifications represent target
operational envelopes to be verified through qualification tests.

---

## 1. Goal

Provide pitmasters with an autonomous, high-precision temperature regulator for charcoal and wood-fueled smokers. The controller continuously reads chamber (pit) and food (meat) temperatures, modulates active forced airflow via a 5V blower fan, and controls a physical servo-actuated damper to prevent convective chimney run-away and enable fine-grained natural draft regulation at low-and-slow temperatures.

The controller must operate safely and autonomously on the ESP32 microcontroller, remaining completely reliable regardless of Wi-Fi or browser connectivity.

---

## 2. Expected Behavior

1. **Power-On & Fail-Safe State**:
   - On boot, reset, or brownout, the blower fan PWM is immediately driven to 0% (OFF) and the servo damper is driven to 0% (fully CLOSED).
   - Sensor health and hardware peripherals are verified before enabling closed-loop regulation.

2. **Dual-Actuator Airflow Modulation (HeaterMeter & Roto-Damper Mode)**:
   - The PID control loop computes an aggregate **Airflow Demand** ($0\text{--}100\%$).
   - **Low Demand (Natural Draft Stage, $0\% \le \text{Demand} \le \text{Threshold}$)**:
     - The blower fan remains OFF ($0\%$).
     - The servo damper modulates smoothly between $0\%$ (closed) and $100\%$ (open).
     - For well-sealed smokers (e.g., Kamados, WSMs, drum cookers), this allows ultra-stable $225^\circ\text{F}$ holding without blowing ash or overshooting.
   - **High Demand (Forced Draft Stage, $\text{Demand} > \text{Threshold}$)**:
     - The servo damper remains fully OPEN ($100\%$).
     - The blower fan activates at its minimum operating speed and modulates linearly up to $100\%$ to aggressively stoke coals during warm-up, setpoint recovery, or high-temperature cooking.
   - **Zero Demand ($0\%$)**:
     - Both fan and damper are fully closed. The closed mechanical damper eliminates the "chimney draft effect" where hot exhaust drafts unmetered air through static fan blades.

3. **Lid Open Detection & Recovery**:
   - A rapid chamber temperature drop (configurable $-\Delta T / \Delta t$) indicates the smoker lid/door has been opened.
   - The controller immediately clamps airflow demand to $0\%$ (fan OFF, damper CLOSED) for a configurable pause duration (e.g. 180s) to prevent oxygen surges from stoking the fire into an uncontrolled blaze.
   - When the pause expires or temperature begins to stabilize, normal closed-loop regulation resumes with anti-windup protection.

4. **Multi-Probe Temperature Acquisition**:
   - Simultaneously reads chamber/pit temperature (for the control loop) and one or more meat/food probes (for cook target alerts).
   - Supports wired thermocouples (K-type via MAX31855/MAX31856 SPI converters) as the primary authoritative reference.
   - Supports pluggable wireless probe adapters (e.g. BLE probes like MEATER or custom RF beacons) behind a unified domain sensor contract.

5. **Local Network Connectivity & Telemetry**:
   - Broadcasts real-time telemetry (pit temp, setpoint, meat temps, fan speed %, damper %, PID components, mode) over local Wi-Fi.
   - Serves an embedded, responsive web control interface accessible on the local network (no cloud or internet access required).

---

## 3. Domain Concepts

- **Airflow Demand ($0\text{--}100\%$)**: The abstract output of the PID control loop representing the total volume of combustion air required.
- **Damper Position ($0\text{--}100\%$)**: The physical aperture percentage of the servo-driven shutter.
- **Blower Speed ($0\text{--}100\%$)**: The duty cycle of the forced-air blower fan.
- **Airflow Threshold ("On Above")**: The demand percentage (default 40–50%) above which the blower fan engages after the damper has reached full aperture.
- **Temperature Reading**: A validated measurement containing value ($^\circ\text{C}$ / $^\circ\text{F}$), sensor role (`Pit`, `Food1`, `Food2`), timestamp/freshness, and diagnostic fault state (`Ok`, `Disconnected`, `ShortToVcc`, `ShortToGnd`, `Stale`).
- **Damper Calibration**: Pulse-width bounds in microseconds ($\text{Pulse}_{\text{close\_us}}$, $\text{Pulse}_{\text{open\_us}}$) and direction inversion flag to accommodate various 3D-printed damper mechanics.
- **Lid Open State**: Temporal state where control output is inhibited due to detected ambient air inrush.

---

## 4. Invariants

- **Autonomous Device Safety**: The ESP32 control loop and fault policies must never depend on Wi-Fi, WebSocket, or browser connection status. If network drops or the web client disconnects, temperature regulation and safety limits continue uninterrupted.
- **Fail-Safe Actuator Shutdown**: Any persistent pit probe fault (disconnection or out-of-range reading) must immediately force fan output to $0\%$ and close the servo damper to starve the fire.
- **Anti-Windup Integration**: The integral term of the PID loop must be clamped during saturation, during lid-open suppression, and when actuator limits are reached.
- **No Direct Hardware in Domain**: Domain calculation of PID, damper/fan coordination, and lid-open state machines must contain zero GPIO, timer, or vendor library calls.
- **Aperture-Before-Forced-Air**: Under no normal operating condition shall the blower fan run while the servo damper is closed. The damper must lead or match blower activation.

---

## 5. Constraints

- **Supply Voltage & Power Compatibility**: Standard **5V DC input** via USB-C or micro-USB ($2.0\text{A}\text{--}3.0\text{A}$ capacity), enabling the system to run on standard phone chargers and USB battery bricks / power banks for outdoor field use. The 5V rail directly powers the 5V blower fan, 5V micro-servo, and feeds the ESP32 onboard 3.3V LDO.
- **Servo Motor Power Isolation & Decoupling**: The 5V micro-servo (MG90S) draws peak current spikes up to $800\text{mA}$ during movement. The 5V bus features bulk decoupling capacitance ($1000\,\mu\text{F}$) and filtering to isolate motor transients from the ESP32.
- **Physical Packaging Form Factors**:
  - **Configuration A (Primary — All-in-One Integrated Pod)**: The 3D-printed housing integrates the blower, servo damper, ESP32 microcontroller, 5V power input, and thermocouple amplifier into a single unit mounted directly to the smoker inlet vent.
  - **Configuration B (Secondary — Modular / Tethered Base Unit)**: A tabletop base unit holds the ESP32 and probe connectors, linking to a slim fan/damper pod on the smoker via an RJ45 umbilical cable utilizing the 4-wire community standard pinout (Pins 3: +5V, 4: GND, 5: +5V Fan, 6: Servo Signal).
- **Parametric OpenSCAD Mechanical Design**: The housing and output nozzle are defined parametrically in OpenSCAD (`cad/smoker_damper.scad`). The fan size (diameter and thickness: 5015, 7530, 9733) and the smoker connection nozzle (round pipe diameter or rectangular duct dimensions) are configurable to adapt to any smoker model (Kamado, WSM, drum, offset).
- **Microcontroller**: Espressif ESP32 dual-core processor using FreeRTOS tasks (Core 0: Network/Web services, Core 1: Deterministic sensor sampling & PID control loop).

---

## 6. Non-Goals

- Direct AC mains heater control (this project is exclusively for charcoal/wood smoker airflow regulation).
- Proprietary cloud-only service lock-in; the device will not require internet access to function.
- Designing custom silicon for wireless probes in Phase 1 (existing wired thermocouples and commercial BLE probes will be integrated first).
- Requiring dedicated 12V automotive batteries or proprietary wall-warts (5V USB power is the target power envelope).

---

## 7. Acceptance Criteria & Evidence Gates

1. **Gate 1 — Actuator Driver & RJ45 Compatibility**:
   - Driven via standard RJ45 port with verified HeaterMeter pinout.
   - Servo moves from 0% (closed, ~1000µs) to 100% (open, ~2000µs) at 50Hz without jitter.
   - Blower fan modulates cleanly from 0% to 100% PWM via low-side MOSFET without back-EMF reset of ESP32.
2. **Gate 2 — Coordinated Airflow Execution**:
   - At $0\%$ demand: Damper closed, fan OFF.
   - At $25\%$ demand (below threshold): Damper at $50\%$, fan OFF.
   - At $50\%$ demand (threshold): Damper at $100\%$, fan OFF.
   - At $75\%$ demand: Damper at $100\%$, fan at $50\%$.
   - At $100\%$ demand: Damper at $100\%$, fan at $100\%$.
3. **Gate 3 — Closed-Loop Smoker Regulation**:
   - Holds pit temperature within $\pm 2^\circ\text{F}$ of setpoint at steady state on a sealed charcoal smoker.
   - Lid open test: temperature drop of $>15^\circ\text{F}$ in $<30\text{s}$ triggers lid-open mode, shutting fan and damper.
4. **Gate 4 — Probe Fault Handling**:
   - Disconnecting the pit thermocouple immediately engages fail-safe clamp (damper closed, fan off) within 1 sample cycle.
5. **Gate 5 — Local Web Telemetry & Control**:
   - Web interface displays live pit/meat temps and damper/fan status updated at $\ge 1\text{Hz}$ over local Wi-Fi.
   - Setpoints and calibration limits can be modified via web UI and persist across reboot in non-volatile storage.

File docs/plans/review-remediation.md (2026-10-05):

# Review remediation: reliable wired-probe control

## North Star

Resolve the October 4 repository review findings while preserving autonomous, offline
ESP32 control with at least one wired K-type pit probe. Trace startup/PWM behavior to
project Gates 1–2, PID recovery to Gate 3, decoded probe faults to Gate 4, and persisted
calibration, safe telemetry, and authenticated controls to Gate 5.

Expected behavior: boot commands calibrated damper closure and fan-off; independent
PWM timers and serialized SPI frames preserve hardware operation; one control task
owns service state; suppressed intervals do not accumulate PID error; configuration
loads after platform startup; copied telemetry outlives its source; web controls require
device-specific credentials and never disclose cloud tokens; servo calibration can be
validated, applied, and persisted. MAX31855 remains the default converter; implement
selectable MAX31856 K-type support rather than claiming an absent driver.

Concepts: owned telemetry snapshot, damper calibration, typed control command, copied
control state, bounded command channel, per-device access credential.

Invariants: inward dependencies, authoritative wired pit source, one-sample fault clamp,
bounded cross-task communication, no network dependency in control, no secret in API
responses or ordinary logs, no direct hardware types crossing application ports.

Constraints: ESP32 Arduino/PlatformIO, 5V hardware/3.3V SPI, existing flash partition,
one optional food converter, existing Python simulator. Physical PWM, probe accuracy,
and smoker +/-2F qualification require a bench; host evidence will not claim them.

Non-goals: CAD redesign, deployment/flashing, cloud product expansion, unrelated UI
redesign. The user explicitly approved retaining the embedded HTML/JavaScript
dashboard as an exception to the prescribed Next.js stack on October 4.

## Architecture plan

Domain: reuse PID, Temperature, SmokerConfig, and DisplayView; add validated damper
calibration and owned telemetry/control messages. Domain must not import Services.
Services: reuse SmokerControlService; explicit initialization, suppression recovery,
calibration application, and command consumption/publication at the control boundary. A service-owned fast
pit-health check inhibits outputs between PID cycles; healthy checks never advance PID.
Ports: reuse sensor/storage/actuator ports; add the related damper calibration operation
and a bounded control-command/state exchange port. No vendor types cross it.
Repositories: none; existing configuration storage port remains sufficient.
Adapters: isolated SPI owner; corrected actuators, MAX converters, NVS, bounded control
exchange; authenticated web boundary with structured parsing and redacted outputs.
The pinned Arduino BLE discovery implementation receives a build-local ownership
repair, checked against the vendor source checksum and executable allocation tests.
No shared SDK files are modified; the application spine remains unchanged.
Controller: construct application ownership after Arduino initialization; wire ports and
schedule control/network tasks, without mutable namespace-level service dependencies.
Client UI: authenticated requests and calibration form in the existing embedded assets.
Tests: production C++ domain/service regression, Arduino driver spies and startup
harness, real simulator HTTP/browser tests, strict host compile and ESP32 build.

## Steps and ownership

1. **Core and application contracts** (independent; blocks integration of steps 2–3).
   Own firmware Domain, Services, test_domain.cpp, a new test_control.cpp, and Python
   Domain/Services plus their tests. Move telemetry value ownership into Domain;
   retain a Ports alias if needed for callers. Add command/state contracts, explicit
   initialize(), calibration, and paused-PID recovery. Tests must kill the previously
   surviving shutdown/range/fault/sign mutations. Step Review: Correctness, Test,
   Architecture.
2. **Hardware and composition** (implements against step 1 contracts).
   Own actuator, sensor, storage, display and runtime adapters; Controller/main.cpp;
   PlatformIO; Arduino-spy tests. Fix timers, first pulse, SPI including MOSI, NVS
   persistence, and display host warning. Implement selectable MAX31856. Compose
   the bounded command channel and place servo housekeeping in the owning task.
   Step Review: Correctness, Test, Architecture.
3. **Authenticated control and calibration UI** (depends on step 1).
   Own firmware network adapter, Python web/config adapters and CLI, dashboard assets,
   HTTP/security/browser tests. No direct cross-task service references. Device AP
   credentials must be provisioned rather than committed; authentication and origin
   checks cover mutations; tokens are write-only. Step Review: Correctness, Test,
   Security, plus Architecture if introducing shared mechanisms.
4. **Integration and verification** (depends on all steps).
   Integrate branches, reconcile seams, update docs and run independent Correctness,
   Architecture, Test, Security review. Resolve new blocking findings and verify all
   software acceptance scenarios; retain explicit bench-only limitations.

Parallel steps use separate worktrees/branches and dedicated scratch paths. The
coordinator owns this plan, final documentation, review scheduling and integration.

## Shared contracts (owned by step 1)

- `Domain::DamperCalibration`: `min_pulse_us`, `max_pulse_us`, `inverted`, validation
  within 500–2500 us with min < max.
- `SmokerConfig`: `servo_min_pulse_us`, `servo_max_pulse_us`, `servo_inverted`.
- `IDamperActuatorPort::configure(const Domain::DamperCalibration&)`.
- Domain-owned `TelemetrySnapshot`, with owned fixed-size strings, accessible through
  the existing Ports name for compatibility.
- `Domain::ControlCommand`: typed setpoint/configuration/lid-pause operations.
- `Domain::ControlState`: copied configuration plus telemetry and persistence status.
- `Services::Ports::IControlChannel`: bounded submit/receive, publish/snapshot by value.
- `SmokerControlService::initialize()` after platform initialization; optional injected
  control channel consumed before each cycle and published afterward. Web never calls
  the mutable service directly. Detailed signatures are to be frozen by step 1 before
  downstream integration.

## Verification plan

North Star behaviors: calibrated safe boot, correct PWM mapping, uninterrupted wired
pit acquisition, fault shutdown, PID recovery, persistent settings, authenticated UI.
Entry points: actual firmware setup/control task via an Arduino boundary harness;
real simulator HTTP/CLI and browser.
External dependencies: GPIO/PWM/SPI/NVS, clock, network, radio/cloud.
Mocks: hardware register/function spies; injected fault frames and device timing.
Fakes: stateful NVS and SPI peripheral boundaries; no fake internal service/client API.
Real integrations: C++ compiler, Arduino framework build, filesystem configuration,
local HTTP server and browser against that server.
Test data: healthy/negative/boundary/out-of-range raw frames, each short/open fault,
missing food probe, active outputs followed by pit failure, 180-second suppression,
valid/invalid calibration, correct/missing/wrong auth, cross-origin requests.
Scenarios: every software criterion above must have executable assertions and negative
cases. Persistence must cross a fresh instance; telemetry must survive stack reuse;
SPI must reject overlapping frame ownership; network failure must not stop control.
Driver: repository test scripts/harnesses with clear exit status and repeatable setup.
Evidence: exact commands/results and acceptance matrix in the completion report.

## Status

Software implementation complete. Independent integration review: PASS, no remaining
findings. All executable software acceptance scenarios pass, including both ESP32
builds and the real simulator/browser flow. Physical Gates 1–5 remain bench work;
full-project verification is PARTIALLY VERIFIED. See the
[completion and verification report](../review-verification.md).

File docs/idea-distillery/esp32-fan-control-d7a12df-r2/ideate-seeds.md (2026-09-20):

# ideate-engine seeds

```yaml
recommendation_id: "rec-acb4628426c773a22c0744f22bf330a3dc12dbd7a96b4ea2085568a9a31a7242"
title: "Retain the controller host and integrate one qualified wireless probe through a replaceable adapter."
rough_note: "Combining the controller with external probes is aligned with the evidence, but no integration partner or migration source is validated. Trade-off: May avoid custom probe development, while introducing external protocol and availability dependencies. Cross-persona support: User Pain & Desires: The author wants one system that controls a fan and monitors temperatures in both the smoke chamber and meat.; User Pain & Desires: The author wants flexibility to use both wired thermocouple probes and wireless temperature probes.; User Pain & Desires: A published wireless-probe API is strongly desired; a custom wireless probe is an exploratory fallback, suggesting a possible unmet integration need.; Market & Landscape: Wireless-probe interoperability is the primary landscape constraint. Compare candidate probes by documented access to temperature readings and integration restrictions before committing to a vendor.; Market & Landscape: The concept combines smoke-chamber fan control with chamber and meat sensing. Its competitive comparison should cover integrated cooking controllers as well as standalone thermometers; differentiation remains unproven.; Market & Landscape: Developing a proprietary wireless probe introduces a separate build-versus-buy decision. It could reduce dependence on third-party interfaces while expanding hardware development and support responsibilities.; Market & Landscape: Chamber sensing, meat sensing, wired thermocouples, and wireless probes create distinct compatibility requirements. Candidate products should be evaluated against each intended use rather than treated as interchangeable.; Leverage & Maintenance: Supporting wired and wireless probes creates an opportunity to reuse temperature-reading and fan-control logic behind a common sensor interface.; Leverage & Maintenance: The preference for a published wireless-probe API signals attention to integration maintenance, but durable vendor support remains unverified.; Leverage & Maintenance: Developing a custom wireless probe could increase control over the interface while adding responsibility for hardware, firmware, calibration, and long-term upkeep. Skeptical conflicts: User Pain & Desires: The evidence is one project note. Priorities are inferred from its emphasis; pain severity, broader demand, willingness to pay, and whether these needs remain unmet are unverified.; Technical Feasibility: This is an architecture-level assessment from one requirements excerpt and a bounded README snapshot. No track is proven operational, and delivery estimates would be speculative. The preference for Track A depends on confirming repository o; Market & Landscape: These findings infer research priorities from one project note. Current vendor capabilities, market size, pricing, customer demand, and commercial intent are unverified.; Leverage & Maintenance: The single README excerpt describes aspirations, not implementation or operating history. It supports identifying opportunities and maintenance exposure, but not concluding that the system is maintainable or durable. Maintenance: Vendor adapters create compatibility obligations; a gateway adds another runtime to operate."
selected_track: "Track C — Synergy/Migration"
host_candidates: []
cited_context:
  - evidence_id: "ev-8df7e13d1fcd33930c33c0d24af2f6f7575bb88c0f18630799205ba089d3843d"
    uri: "file:///home/awbs/projects/esp32-fan-control/README.md"
    sha256: "f0ce46891a037c141d4c4048652bd5a30197325b22d6056706b44e7d82b9eb12"
    byte_start: 70
    byte_end: 459
    line_start: 4
    line_end: 4
    text: "uses a microcontroller to control a fan and read temperature sensors in smoke chamber and in meat.  Should support thermocouple wired probes as well as wireless probes.  One idea is the meater probes, but research other available wireless temperature sensors.  if any have a published api, that would be amazing.  a sub project could be a wireless probe circuit that we develop ourselves."
```

```yaml
recommendation_id: "rec-7d7f89dbf8d0ad8decef5964e8d380a3bfa9bf8975313cf9794defb725b3e4a9"
title: "Create a separate application for temperature history, status, and bounded configuration commands."
rough_note: "A companion application is technically plausible, but its need and device interface are unestablished. Trade-off: Allows an independent interface lifecycle but adds deployment and connectivity complexity. Cross-persona support: User Pain & Desires: The author wants one system that controls a fan and monitors temperatures in both the smoke chamber and meat.; User Pain & Desires: The author wants flexibility to use both wired thermocouple probes and wireless temperature probes.; User Pain & Desires: A published wireless-probe API is strongly desired; a custom wireless probe is an exploratory fallback, suggesting a possible unmet integration need.; Market & Landscape: Wireless-probe interoperability is the primary landscape constraint. Compare candidate probes by documented access to temperature readings and integration restrictions before committing to a vendor.; Market & Landscape: The concept combines smoke-chamber fan control with chamber and meat sensing. Its competitive comparison should cover integrated cooking controllers as well as standalone thermometers; differentiation remains unproven.; Market & Landscape: Developing a proprietary wireless probe introduces a separate build-versus-buy decision. It could reduce dependence on third-party interfaces while expanding hardware development and support responsibilities.; Market & Landscape: Chamber sensing, meat sensing, wired thermocouples, and wireless probes create distinct compatibility requirements. Candidate products should be evaluated against each intended use rather than treated as interchangeable.; Leverage & Maintenance: Supporting wired and wireless probes creates an opportunity to reuse temperature-reading and fan-control logic behind a common sensor interface.; Leverage & Maintenance: The preference for a published wireless-probe API signals attention to integration maintenance, but durable vendor support remains unverified.; Leverage & Maintenance: Developing a custom wireless probe could increase control over the interface while adding responsibility for hardware, firmware, calibration, and long-term upkeep. Skeptical conflicts: User Pain & Desires: The evidence is one project note. Priorities are inferred from its emphasis; pain severity, broader demand, willingness to pay, and whether these needs remain unmet are unverified.; Technical Feasibility: This is an architecture-level assessment from one requirements excerpt and a bounded README snapshot. No track is proven operational, and delivery estimates would be speculative. The preference for Track A depends on confirming repository o; Market & Landscape: These findings infer research priorities from one project note. Current vendor capabilities, market size, pricing, customer demand, and commercial intent are unverified.; Leverage & Maintenance: The single README excerpt describes aspirations, not implementation or operating history. It supports identifying opportunities and maintenance exposure, but not concluding that the system is maintainable or durable. Maintenance: Requires coordinating application, firmware, and protocol versions."
selected_track: "Track B — Standalone Application"
host_candidates: []
cited_context:
  - evidence_id: "ev-8df7e13d1fcd33930c33c0d24af2f6f7575bb88c0f18630799205ba089d3843d"
    uri: "file:///home/awbs/projects/esp32-fan-control/README.md"
    sha256: "f0ce46891a037c141d4c4048652bd5a30197325b22d6056706b44e7d82b9eb12"
    byte_start: 70
    byte_end: 459
    line_start: 4
    line_end: 4
    text: "uses a microcontroller to control a fan and read temperature sensors in smoke chamber and in meat.  Should support thermocouple wired probes as well as wireless probes.  One idea is the meater probes, but research other available wireless temperature sensors.  if any have a published api, that would be amazing.  a sub project could be a wireless probe circuit that we develop ourselves."
```

```yaml
recommendation_id: "rec-bd369e8a00bf6f2cf36a62ddb4c115e29df26a07ee6ce22e2ee9d8a1d70052b2"
title: "Create an independently deployed web application with a device adapter."
rough_note: "Separate hosting can serve the stated local-network workflow if a supported controller interface exists. Trade-off: Independent UI deployment adds hosting and setup obligations. Cross-persona support: User Pain & Desires: The stated product goal is fan control for a charcoal- or wood-fueled smoker. The specific user problem this would solve is not documented.; User Pain & Desires: Users are intended to access a control app over local Wi-Fi; a web interface is a tentative preference.; User Pain & Desires: Reducing trips to the smoker or hands-on adjustment is a plausible unmet need behind network-accessible fan control, but remains unverified.; Market & Landscape: The stated use case is fan control for charcoal or wood smokers. This identifies an application niche, but provides no evidence of customer demand or willingness to pay.; Market & Landscape: Local Wi-Fi access is an explicit intended capability; a web interface is tentative. Adoption may depend on network availability where the smoker operates.; Market & Landscape: Competitive positioning remains undetermined: the ESP32 project name and proposed control app do not establish a differentiated customer benefit.; Leverage & Maintenance: Smoker fan control offers potential to reduce repeated manual adjustments, but the evidence establishes intended purpose rather than demonstrated automation or time savings.; Leverage & Maintenance: The proposed web app and local Wi-Fi access could make control more convenient, while adding interface and connectivity maintenance responsibilities.; Leverage & Maintenance: Local-network reachability suggests an opportunity for operation without an external service, but long-term autonomy and maintainability remain unproven. Skeptical conflicts: User Pain & Desires: All evidence comes from one brief project README. Priorities reflect stated product intent and inference, not measured user pain. No customer testimony, observed behavior, or validation of unmet demand is supplied.; Technical Feasibility: The evidence establishes product intent only. Hardware capacity, implementation maturity, effort, and operational reliability cannot be determined. The preference for Track A reflects the single identified repository and initial scope, not ; Market & Landscape: The evidence supports a use case and intended access model, but cannot establish market attractiveness, competitive advantage, or commercial readiness.; Leverage & Maintenance: The packet contains three short excerpts from one README. These support intended scope, not implementation maturity, maintenance cost, reliability, or realized savings. Maintenance: Requires compatibility testing across independently released application and firmware versions."
selected_track: "Track B — Standalone Application"
host_candidates: []
cited_context:
  - evidence_id: "ev-17f44bb72153572b7b22a3575934efc9a640732ddae90d9fd92ac89aea2183c0"
    uri: "file:///home/awbs/projects/esp32-fan-control/README.md"
    sha256: "f0ce46891a037c141d4c4048652bd5a30197325b22d6056706b44e7d82b9eb12"
    byte_start: 460
    byte_end: 574
    line_start: 6
    line_end: 6
    text: "there should also be a control app, likely web based.  the whole thing should be reachable on local wifi network."
  - evidence_id: "ev-5ccbce1b8da7289117731890269cecc7e30f687beae49ebb8d00968ead2f345c"
    uri: "file:///home/awbs/projects/esp32-fan-control/README.md"
    sha256: "f0ce46891a037c141d4c4048652bd5a30197325b22d6056706b44e7d82b9eb12"
    byte_start: 0
    byte_end: 20
    line_start: 1
    line_end: 1
    text: "# esp32-fan-control"
  - evidence_id: "ev-6c650ccb4641754889e981644889993ad422525ddcc31c1f2f35a33bfc35f4e8"
    uri: "file:///home/awbs/projects/esp32-fan-control/README.md"
    sha256: "f0ce46891a037c141d4c4048652bd5a30197325b22d6056706b44e7d82b9eb12"
    byte_start: 20
    byte_end: 69
    line_start: 2
    line_end: 2
    text: "fan controller for charcoal or wood based smoker"
```

```yaml
recommendation_id: "rec-39983cc2026f3efd4ea235307e8792bb436e2de68e2eae4648ab66955b81dfc1"
title: "Build a wired-probe control loop first, then add independently validated wireless sensor adapters."
rough_note: "The repository's stated purpose directly matches the proposed controller, but implementation readiness is unknown. Trade-off: Direct alignment with the objective, with embedded debugging and hardware qualification required. Cross-persona support: User Pain & Desires: The author wants one system that controls a fan and monitors temperatures in both the smoke chamber and meat.; User Pain & Desires: The author wants flexibility to use both wired thermocouple probes and wireless temperature probes.; User Pain & Desires: A published wireless-probe API is strongly desired; a custom wireless probe is an exploratory fallback, suggesting a possible unmet integration need.; Market & Landscape: Wireless-probe interoperability is the primary landscape constraint. Compare candidate probes by documented access to temperature readings and integration restrictions before committing to a vendor.; Market & Landscape: The concept combines smoke-chamber fan control with chamber and meat sensing. Its competitive comparison should cover integrated cooking controllers as well as standalone thermometers; differentiation remains unproven.; Market & Landscape: Developing a proprietary wireless probe introduces a separate build-versus-buy decision. It could reduce dependence on third-party interfaces while expanding hardware development and support responsibilities.; Market & Landscape: Chamber sensing, meat sensing, wired thermocouples, and wireless probes create distinct compatibility requirements. Candidate products should be evaluated against each intended use rather than treated as interchangeable.; Leverage & Maintenance: Supporting wired and wireless probes creates an opportunity to reuse temperature-reading and fan-control logic behind a common sensor interface.; Leverage & Maintenance: The preference for a published wireless-probe API signals attention to integration maintenance, but durable vendor support remains unverified.; Leverage & Maintenance: Developing a custom wireless probe could increase control over the interface while adding responsibility for hardware, firmware, calibration, and long-term upkeep. Skeptical conflicts: User Pain & Desires: The evidence is one project note. Priorities are inferred from its emphasis; pain severity, broader demand, willingness to pay, and whether these needs remain unmet are unverified.; Technical Feasibility: This is an architecture-level assessment from one requirements excerpt and a bounded README snapshot. No track is proven operational, and delivery estimates would be speculative. The preference for Track A depends on confirming repository o; Market & Landscape: These findings infer research priorities from one project note. Current vendor capabilities, market size, pricing, customer demand, and commercial intent are unverified.; Leverage & Maintenance: The single README excerpt describes aspirations, not implementation or operating history. It supports identifying opportunities and maintenance exposure, but not concluding that the system is maintainable or durable. Maintenance: One firmware lifecycle; each supported probe and fan interface adds hardware-specific maintenance."
selected_track: "Track A — In-Repo Enhancement"
host_candidates: ["esp32-fan-control"]
cited_context:
  - evidence_id: "ev-8df7e13d1fcd33930c33c0d24af2f6f7575bb88c0f18630799205ba089d3843d"
    uri: "file:///home/awbs/projects/esp32-fan-control/README.md"
    sha256: "f0ce46891a037c141d4c4048652bd5a30197325b22d6056706b44e7d82b9eb12"
    byte_start: 70
    byte_end: 459
    line_start: 4
    line_end: 4
    text: "uses a microcontroller to control a fan and read temperature sensors in smoke chamber and in meat.  Should support thermocouple wired probes as well as wireless probes.  One idea is the meater probes, but research other available wireless temperature sensors.  if any have a published api, that would be amazing.  a sub project could be a wireless probe circuit that we develop ourselves."
```

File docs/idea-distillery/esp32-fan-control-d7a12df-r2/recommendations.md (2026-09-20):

# Idea Distillery Recommendations

- Run ID: esp32&#x2D;fan&#x2D;control&#x2D;d7a12df&#x2D;r2
- Schema: run&#x2D;manifest&#x2D;v1
- Provider: codex
- Model: gpt&#x2D;6&#x2D;astra
- Prompt version: persona&#x2D;prompts&#x2D;v1
- Workspace binding: 8c20034269eb791bd0af5af69577d4f8d463dc8dbd63d556be24e39b1893c57e

## Inputs

- &#x2F;home&#x2F;awbs&#x2F;projects&#x2F;esp32&#x2D;fan&#x2D;control&#x2F;README&#x2E;md — f0ce46891a037c141d4c4048652bd5a30197325b22d6056706b44e7d82b9eb12

## Agent outcomes

### isolated&#x2D;001

- User Pain &#x26; Desires: success
  - The author wants one system that controls a fan and monitors temperatures in both the smoke chamber and meat&#x2E;
  - The author wants flexibility to use both wired thermocouple probes and wireless temperature probes&#x2E;
  - A published wireless&#x2D;probe API is strongly desired&#x3B; a custom wireless probe is an exploratory fallback&#x2C; suggesting a possible unmet integration need&#x2E;
- Technical Feasibility: success
  - Track A is the strongest provisional fit&#x3A; extend esp32&#x2D;fan&#x2D;control with local temperature acquisition and fan control&#x2E; The snapshot establishes intent and a README&#x2C; but does not establish existing firmware&#x2C; hardware interfaces&#x2C; or tests&#x2E;
  - Track B is conditional as a monitoring and configuration application&#x2E; Delivering the complete objective still requires a physical controller and an explicit device communication contract&#x2E;
  - Track C is conditional on proving a wireless integration&#x2E; MEATER is only a candidate in the evidence&#x3B; no usable API&#x2C; protocol&#x2C; or compatible model is established&#x2E; A custom wireless probe is a separate hardware development effort&#x2E;
- Market &#x26; Landscape: success
  - Wireless&#x2D;probe interoperability is the primary landscape constraint&#x2E; Compare candidate probes by documented access to temperature readings and integration restrictions before committing to a vendor&#x2E;
  - The concept combines smoke&#x2D;chamber fan control with chamber and meat sensing&#x2E; Its competitive comparison should cover integrated cooking controllers as well as standalone thermometers&#x3B; differentiation remains unproven&#x2E;
  - Developing a proprietary wireless probe introduces a separate build&#x2D;versus&#x2D;buy decision&#x2E; It could reduce dependence on third&#x2D;party interfaces while expanding hardware development and support responsibilities&#x2E;
  - Chamber sensing&#x2C; meat sensing&#x2C; wired thermocouples&#x2C; and wireless probes create distinct compatibility requirements&#x2E; Candidate products should be evaluated against each intended use rather than treated as interchangeable&#x2E;
- Leverage &#x26; Maintenance: success
  - Supporting wired and wireless probes creates an opportunity to reuse temperature&#x2D;reading and fan&#x2D;control logic behind a common sensor interface&#x2E;
  - The preference for a published wireless&#x2D;probe API signals attention to integration maintenance&#x2C; but durable vendor support remains unverified&#x2E;
  - Developing a custom wireless probe could increase control over the interface while adding responsibility for hardware&#x2C; firmware&#x2C; calibration&#x2C; and long&#x2D;term upkeep&#x2E;

### theme&#x2D;001

- User Pain &#x26; Desires: success
  - The stated product goal is fan control for a charcoal&#x2D; or wood&#x2D;fueled smoker&#x2E; The specific user problem this would solve is not documented&#x2E;
  - Users are intended to access a control app over local Wi&#x2D;Fi&#x3B; a web interface is a tentative preference&#x2E;
  - Reducing trips to the smoker or hands&#x2D;on adjustment is a plausible unmet need behind network&#x2D;accessible fan control&#x2C; but remains unverified&#x2E;
- Technical Feasibility: success
  - Track A is conditionally feasible and the provisional preference&#x3A; develop the local&#x2D;network control interface within esp32&#x2D;fan&#x2D;control&#x2E; The snapshot establishes intent&#x2C; but provides no implementation evidence&#x2E;
  - Track B is conditionally feasible&#x2C; but a standalone application still depends on controller firmware and a defined device protocol&#x2E; No such integration contract is evidenced&#x2E;
  - Track C is unsupported as an immediate reuse or migration project&#x3A; the packet identifies no second host&#x2C; reusable implementation&#x2C; or existing application to migrate&#x2E;
  - All implementation paths require a device&#x2D;level failure policy before live smoker control&#x2E; Browser or network availability should not be required to handle sensor faults or enforce output limits&#x2E;
- Market &#x26; Landscape: success
  - The stated use case is fan control for charcoal or wood smokers&#x2E; This identifies an application niche&#x2C; but provides no evidence of customer demand or willingness to pay&#x2E;
  - Local Wi&#x2D;Fi access is an explicit intended capability&#x3B; a web interface is tentative&#x2E; Adoption may depend on network availability where the smoker operates&#x2E;
  - Competitive positioning remains undetermined&#x3A; the ESP32 project name and proposed control app do not establish a differentiated customer benefit&#x2E;
- Leverage &#x26; Maintenance: success
  - Smoker fan control offers potential to reduce repeated manual adjustments&#x2C; but the evidence establishes intended purpose rather than demonstrated automation or time savings&#x2E;
  - The proposed web app and local Wi&#x2D;Fi access could make control more convenient&#x2C; while adding interface and connectivity maintenance responsibilities&#x2E;
  - Local&#x2D;network reachability suggests an opportunity for operation without an external service&#x2C; but long&#x2D;term autonomy and maintainability remain unproven&#x2E;

## Skeptical audit

- Conflict: The evidence is one project note&#x2E; Priorities are inferred from its emphasis&#x3B; pain severity&#x2C; broader demand&#x2C; willingness to pay&#x2C; and whether these needs remain unmet are unverified&#x2E;
- Conflict: This is an architecture&#x2D;level assessment from one requirements excerpt and a bounded README snapshot&#x2E; No track is proven operational&#x2C; and delivery estimates would be speculative&#x2E; The preference for Track A depends on confirming repository ownership and hardware scope&#x2E;
- Conflict: These findings infer research priorities from one project note&#x2E; Current vendor capabilities&#x2C; market size&#x2C; pricing&#x2C; customer demand&#x2C; and commercial intent are unverified&#x2E;
- Conflict: The single README excerpt describes aspirations&#x2C; not implementation or operating history&#x2E; It supports identifying opportunities and maintenance exposure&#x2C; but not concluding that the system is maintainable or durable&#x2E;
- Conflict: All evidence comes from one brief project README&#x2E; Priorities reflect stated product intent and inference&#x2C; not measured user pain&#x2E; No customer testimony&#x2C; observed behavior&#x2C; or validation of unmet demand is supplied&#x2E;
- Conflict: The evidence establishes product intent only&#x2E; Hardware capacity&#x2C; implementation maturity&#x2C; effort&#x2C; and operational reliability cannot be determined&#x2E; The preference for Track A reflects the single identified repository and initial scope&#x2C; not verified technical superiority&#x2E;
- Conflict: The evidence supports a use case and intended access model&#x2C; but cannot establish market attractiveness&#x2C; competitive advantage&#x2C; or commercial readiness&#x2E;
- Conflict: The packet contains three short excerpts from one README&#x2E; These support intended scope&#x2C; not implementation maturity&#x2C; maintenance cost&#x2C; reliability&#x2C; or realized savings&#x2E;
- Challenged assumption: The API preference reflects a desire to integrate probe readings into the controller&#x2E; — Treating custom hardware as a committed requirement could expand scope prematurely&#x2E;
- Challenged assumption: A separate user interface provides value beyond the embedded controller&#x2E; — Duplicated control logic and dependence on application or network availability&#x2E;
- Challenged assumption: The named repository is the intended home for the controller&#x2E; — Sensor failures or incorrect fan actuation could produce unsafe temperatures&#x2E;
- Challenged assumption: Wireless probes must provide readings sufficiently timely and reliable for the intended use&#x2E; — Protocol changes&#x2C; stale readings&#x2C; radio attenuation&#x2C; and custom&#x2D;probe thermal or power constraints&#x2E;
- Challenged assumption: A custom probe would be developed and maintained by the project team&#x2E; — Probe development could consume resources needed for the fan controller&#x2E;
- Challenged assumption: Both sensing locations and both connection methods remain in scope&#x2E; — A selected probe may satisfy only part of the intended operating requirements&#x2E;
- Challenged assumption: The controller needs programmatic access to wireless temperature readings&#x2E; — An inaccessible or unstable interface could prevent integration or create ongoing maintenance costs&#x2E;
- Challenged assumption: The intended setting is smoker cooking&#x2E; — Combining these functions may offer insufficient advantage over available alternatives&#x2E;
- Challenged assumption: A documented&#x2C; supported interface would reduce integration uncertainty&#x2E; — API changes&#x2C; discontinued support&#x2C; or cloud dependencies could require ongoing repairs&#x2E;
- Challenged assumption: Different probe types can supply readings through a shared contract&#x2E; — Probe&#x2D;specific timing and failure behavior could complicate the interface&#x2E;
- Challenged assumption: The proposed circuit would become a maintained component of the system&#x2E; — A separate hardware effort could divert resources from the core fan controller&#x2E;
- Challenged assumption: Current operation requires inconvenient physical adjustments&#x2E; — Inferring convenience as the main motivation could miss goals such as experimentation or control precision&#x2E;
- Challenged assumption: Network control is motivated by convenience&#x2E; — Inferring convenience as the main motivation could miss goals such as experimentation or control precision&#x2E;
- Challenged assumption: A separate local host is acceptable to users&#x2E; — Separate installation&#x2C; device discovery&#x2C; and protocol&#x2D;version compatibility increase maintenance&#x2E;
- Challenged assumption: The initial scope is one controller and a browser interface on the same local network&#x2E; — Device resources may constrain serving a web interface alongside control duties&#x2E;
- Challenged assumption: The proposed application can affect fan operation&#x2E; — Stale commands&#x2C; sensor faults&#x2C; or connection loss could produce unintended fan output&#x2E;
- Challenged assumption: Users would access the controller over Wi&#x2D;Fi during cooking&#x2E; — Poor network coverage at the smoker could limit app usability&#x2E;
- Challenged assumption: Control and required assets could reside locally&#x2E; — Unspecified external dependencies or recovery procedures could undermine continued operation&#x2E;
- Challenged assumption: Fan control would replace some manual intervention&#x2E; — A controller requiring frequent supervision may deliver limited effort savings&#x2E;
- Challenged assumption: The proposed app and network access will be implemented&#x2E; — Connection setup and app compatibility could create recurring support work&#x2E;
- Workspace overlap isolated&#x2D;001: Technical host candidates overlap the supplied workspace snapshot&#x2E;
- Workspace overlap theme&#x2D;001: No in&#x2D;workspace host candidate was proposed&#x2E;

## New Standalone Projects

### 1. Retain the controller host and integrate one qualified wireless probe through a replaceable adapter&#x2E;

- Recommendation ID: rec&#x2D;acb4628426c773a22c0744f22bf330a3dc12dbd7a96b4ea2085568a9a31a7242
- Theme: isolated&#x2D;001
- Confidence: low
- Effort: medium
- Maintenance: Vendor adapters create compatibility obligations&#x3B; a gateway adds another runtime to operate&#x2E;
- Rationale: Combining the controller with external probes is aligned with the evidence&#x2C; but no integration partner or migration source is validated&#x2E; Trade&#x2D;off&#x3A; May avoid custom probe development&#x2C; while introducing external protocol and availability dependencies&#x2E; Cross&#x2D;persona support&#x3A; User Pain &#x26; Desires&#x3A; The author wants one system that controls a fan and monitors temperatures in both the smoke chamber and meat&#x2E;&#x3B; User Pain &#x26; Desires&#x3A; The author wants flexibility to use both wired thermocouple probes and wireless temperature probes&#x2E;&#x3B; User Pain &#x26; Desires&#x3A; A published wireless&#x2D;probe API is strongly desired&#x3B; a custom wireless probe is an exploratory fallback&#x2C; suggesting a possible unmet integration need&#x2E;&#x3B; Market &#x26; Landscape&#x3A; Wireless&#x2D;probe interoperability is the primary landscape constraint&#x2E; Compare candidate probes by documented access to temperature readings and integration restrictions before committing to a vendor&#x2E;&#x3B; Market &#x26; Landscape&#x3A; The concept combines smoke&#x2D;chamber fan control with chamber and meat sensing&#x2E; Its competitive comparison should cover integrated cooking controllers as well as standalone thermometers&#x3B; differentiation remains unproven&#x2E;&#x3B; Market &#x26; Landscape&#x3A; Developing a proprietary wireless probe introduces a separate build&#x2D;versus&#x2D;buy decision&#x2E; It could reduce dependence on third&#x2D;party interfaces while expanding hardware development and support responsibilities&#x2E;&#x3B; Market &#x26; Landscape&#x3A; Chamber sensing&#x2C; meat sensing&#x2C; wired thermocouples&#x2C; and wireless probes create distinct compatibility requirements&#x2E; Candidate products should be evaluated against each intended use rather than treated as interchangeable&#x2E;&#x3B; Leverage &#x26; Maintenance&#x3A; Supporting wired and wireless probes creates an opportunity to reuse temperature&#x2D;reading and fan&#x2D;control logic behind a common sensor interface&#x2E;&#x3B; Leverage &#x26; Maintenance&#x3A; The preference for a published wireless&#x2D;probe API signals attention to integration maintenance&#x2C; but durable vendor support remains unverified&#x2E;&#x3B; Leverage &#x26; Maintenance&#x3A; Developing a custom wireless probe could increase control over the interface while adding responsibility for hardware&#x2C; firmware&#x2C; calibration&#x2C; and long&#x2D;term upkeep&#x2E; Skeptical conflicts&#x3A; User Pain &#x26; Desires&#x3A; The evidence is one project note&#x2E; Priorities are inferred from its emphasis&#x3B; pain severity&#x2C; broader demand&#x2C; willingness to pay&#x2C; and whether these needs remain unmet are unverified&#x2E;&#x3B; Technical Feasibility&#x3A; This is an architecture&#x2D;level assessment from one requirements excerpt and a bounded README snapshot&#x2E; No track is proven operational&#x2C; and delivery estimates would be speculative&#x2E; The preference for Track A depends on confirming repository o&#x3B; Market &#x26; Landscape&#x3A; These findings infer research priorities from one project note&#x2E; Current vendor capabilities&#x2C; market size&#x2C; pricing&#x2C; customer demand&#x2C; and commercial intent are unverified&#x2E;&#x3B; Leverage &#x26; Maintenance&#x3A; The single README excerpt describes aspirations&#x2C; not implementation or operating history&#x2E; It supports identifying opportunities and maintenance exposure&#x2C; but not concluding that the system is maintainable or durable&#x2E;
- Track: Track C &#x2014; Synergy&#x2F;Migration
- Hosts: none
- Citations: ev&#x2D;8df7e13d1fcd33930c33c0d24af2f6f7575bb88c0f18630799205ba089d3843d

### 2. Create a separate application for temperature history&#x2C; status&#x2C; and bounded configuration commands&#x2E;

- Recommendation ID: rec&#x2D;7d7f89dbf8d0ad8decef5964e8d380a3bfa9bf8975313cf9794defb725b3e4a9
- Theme: isolated&#x2D;001
- Confidence: low
- Effort: large
- Maintenance: Requires coordinating application&#x2C; firmware&#x2C; and protocol versions&#x2E;
- Rationale: A companion application is technically plausible&#x2C; but its need and device interface are unestablished&#x2E; Trade&#x2D;off&#x3A; Allows an independent interface lifecycle but adds deployment and connectivity complexity&#x2E; Cross&#x2D;persona support&#x3A; User Pain &#x26; Desires&#x3A; The author wants one system that controls a fan and monitors temperatures in both the smoke chamber and meat&#x2E;&#x3B; User Pain &#x26; Desires&#x3A; The author wants flexibility to use both wired thermocouple probes and wireless temperature probes&#x2E;&#x3B; User Pain &#x26; Desires&#x3A; A published wireless&#x2D;probe API is strongly desired&#x3B; a custom wireless probe is an exploratory fallback&#x2C; suggesting a possible unmet integration need&#x2E;&#x3B; Market &#x26; Landscape&#x3A; Wireless&#x2D;probe interoperability is the primary landscape constraint&#x2E; Compare candidate probes by documented access to temperature readings and integration restrictions before committing to a vendor&#x2E;&#x3B; Market &#x26; Landscape&#x3A; The concept combines smoke&#x2D;chamber fan control with chamber and meat sensing&#x2E; Its competitive comparison should cover integrated cooking controllers as well as standalone thermometers&#x3B; differentiation remains unproven&#x2E;&#x3B; Market &#x26; Landscape&#x3A; Developing a proprietary wireless probe introduces a separate build&#x2D;versus&#x2D;buy decision&#x2E; It could reduce dependence on third&#x2D;party interfaces while expanding hardware development and support responsibilities&#x2E;&#x3B; Market &#x26; Landscape&#x3A; Chamber sensing&#x2C; meat sensing&#x2C; wired thermocouples&#x2C; and wireless probes create distinct compatibility requirements&#x2E; Candidate products should be evaluated against each intended use rather than treated as interchangeable&#x2E;&#x3B; Leverage &#x26; Maintenance&#x3A; Supporting wired and wireless probes creates an opportunity to reuse temperature&#x2D;reading and fan&#x2D;control logic behind a common sensor interface&#x2E;&#x3B; Leverage &#x26; Maintenance&#x3A; The preference for a published wireless&#x2D;probe API signals attention to integration maintenance&#x2C; but durable vendor support remains unverified&#x2E;&#x3B; Leverage &#x26; Maintenance&#x3A; Developing a custom wireless probe could increase control over the interface while adding responsibility for hardware&#x2C; firmware&#x2C; calibration&#x2C; and long&#x2D;term upkeep&#x2E; Skeptical conflicts&#x3A; User Pain &#x26; Desires&#x3A; The evidence is one project note&#x2E; Priorities are inferred from its emphasis&#x3B; pain severity&#x2C; broader demand&#x2C; willingness to pay&#x2C; and whether these needs remain unmet are unverified&#x2E;&#x3B; Technical Feasibility&#x3A; This is an architecture&#x2D;level assessment from one requirements excerpt and a bounded README snapshot&#x2E; No track is proven operational&#x2C; and delivery estimates would be speculative&#x2E; The preference for Track A depends on confirming repository o&#x3B; Market &#x26; Landscape&#x3A; These findings infer research priorities from one project note&#x2E; Current vendor capabilities&#x2C; market size&#x2C; pricing&#x2C; customer demand&#x2C; and commercial intent are unverified&#x2E;&#x3B; Leverage &#x26; Maintenance&#x3A; The single README excerpt describes aspirations&#x2C; not implementation or operating history&#x2E; It supports identifying opportunities and maintenance exposure&#x2C; but not concluding that the system is maintainable or durable&#x2E;
- Track: Track B &#x2014; Standalone Application
- Hosts: none
- Citations: ev&#x2D;8df7e13d1fcd33930c33c0d24af2f6f7575bb88c0f18630799205ba089d3843d
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

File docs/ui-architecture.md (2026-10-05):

# Agent UI Architecture Contract

## ESP32 embedded-dashboard exception

On 2026-10-04 the user explicitly approved retaining the existing HTML/CSS/JavaScript
dashboard in `firmware/data` for the ESP32 remediation work. It is served from flash
without a Node server, cloud dependency, or runtime package downloads. The prescribed
Next.js/TypeScript/Tailwind/shadcn stack and `Clients/web` placement do not apply to
this embedded client. API boundaries, authentication, accessible forms, error/loading
states, and verification against the real backend still apply.

This contract governs **browser-based user interface** construction. It defines the stack,
patterns, and structure for web clients that consume backend APIs.

A web client is a `Clients` entry in the Architecture Canon. [architecture.md](architecture.md) governs the
client's relationship to the backend; this contract governs the client's internals.

For verification requirements, see [verification.md](verification.md). The UI is part of the system — not a
separate application.

## Objective

Build accessible, maintainable web interfaces using a constrained set of tools and patterns.

UI clients:

- MUST consume backend APIs as their only data source.
- MUST render correctly in current versions of Chrome, Firefox, Safari, and Edge.
- MUST support light and dark themes.
- MUST start and function from a single documented command.
- SHOULD remain understandable as they grow.

---

# Placement

A web client lives under `Clients`:

```text
Clients/web/
```

The client MUST NOT import backend Domain, Services, Ports, Adapters, or Controller code.
It communicates with the system only through published transport endpoints.

All paths in this contract are relative to the client root.

---

# Stack

## Framework

**Next.js** with App Router.

- Server Components MUST own initial page data.
- Client Components MUST be limited to interactive elements.
- Routing MUST be file-based.
- TypeScript MUST run in strict mode.

Other frameworks introduce unnecessary divergence.
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

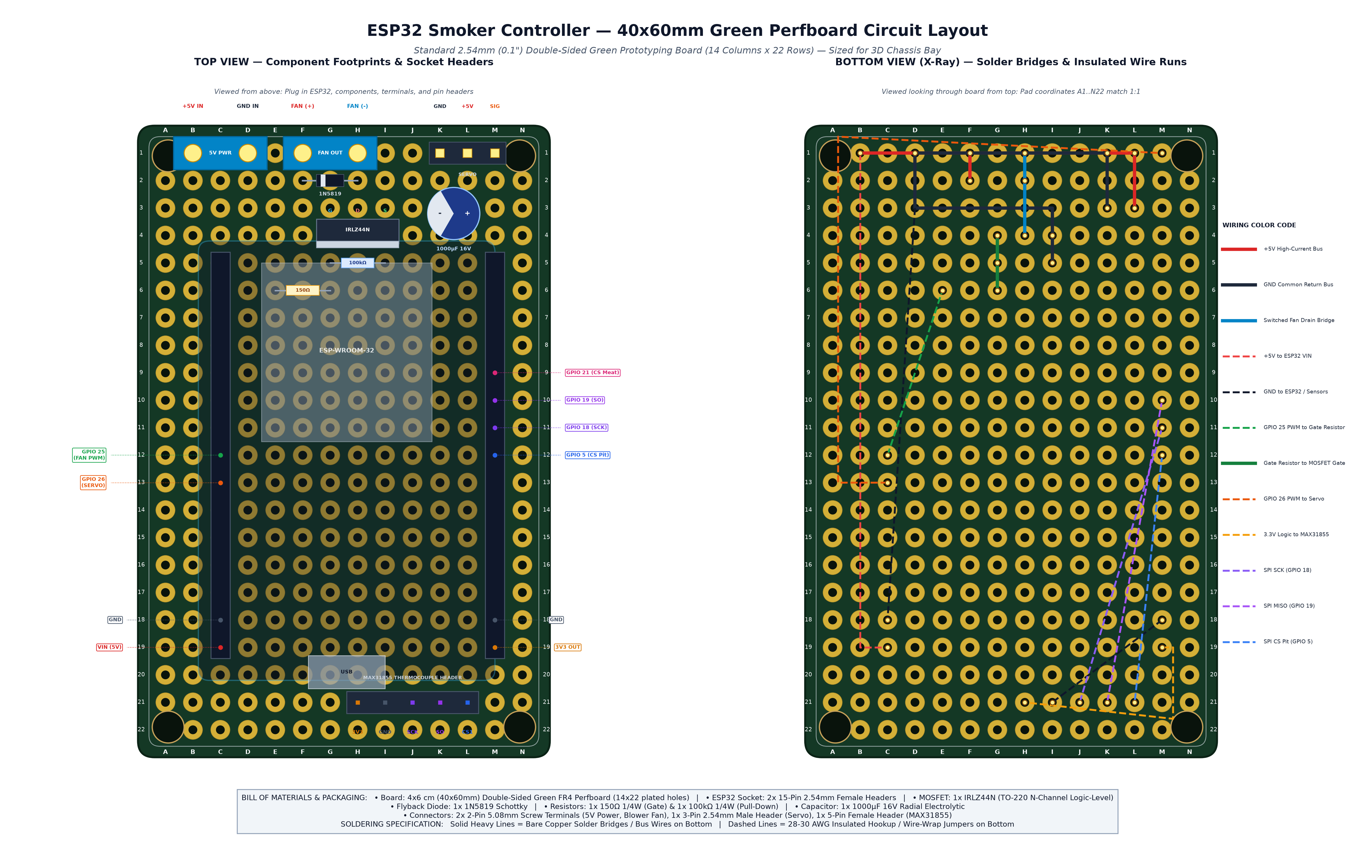
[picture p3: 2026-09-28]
docs/images/perfboard_circuit_layout.png

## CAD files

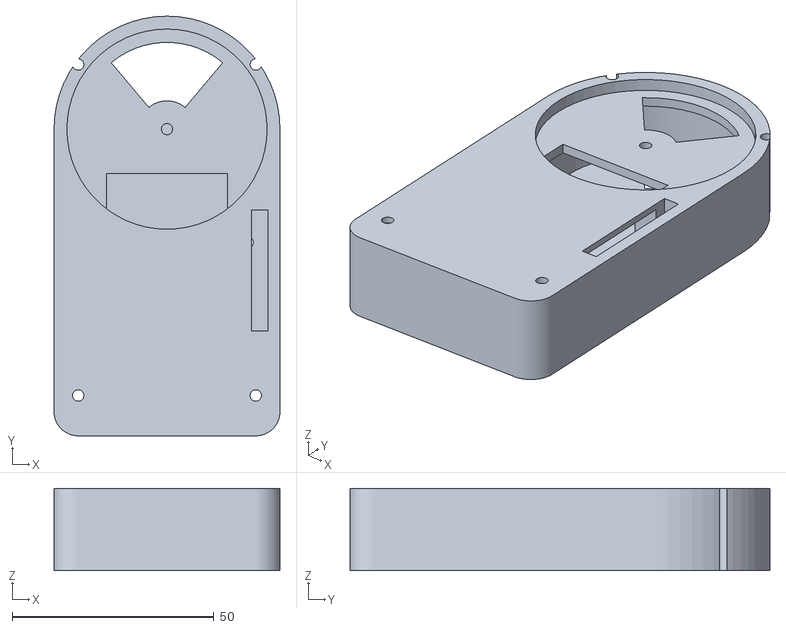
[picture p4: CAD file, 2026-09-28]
cad/stl/rotodamper_base.stl
56.0 x 104.0 x 20.4

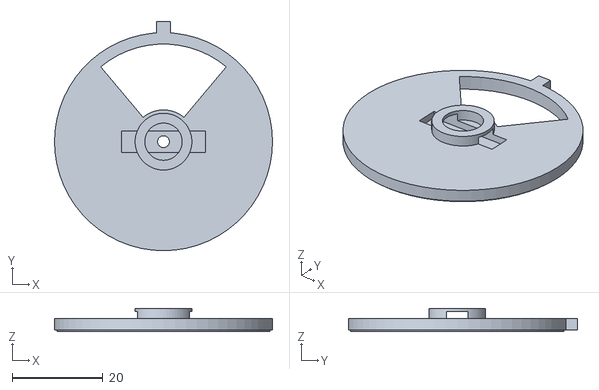
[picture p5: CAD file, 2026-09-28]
cad/stl/rotodamper_disc.stl
48.0 x 50.5 x 5.10

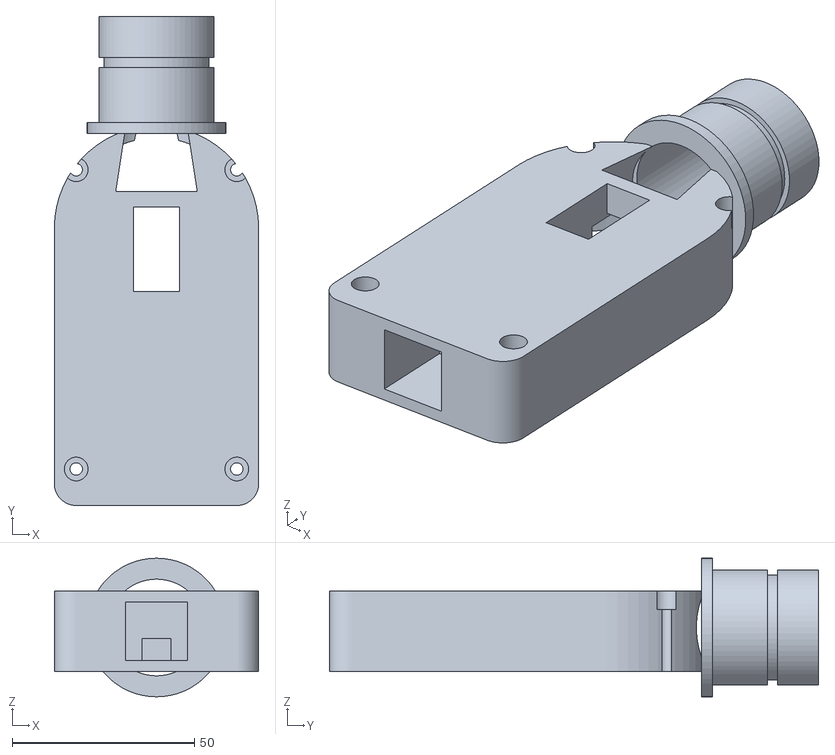
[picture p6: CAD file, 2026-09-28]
cad/stl/rotodamper_cap.stl
56.0 x 134.0 x 38.0

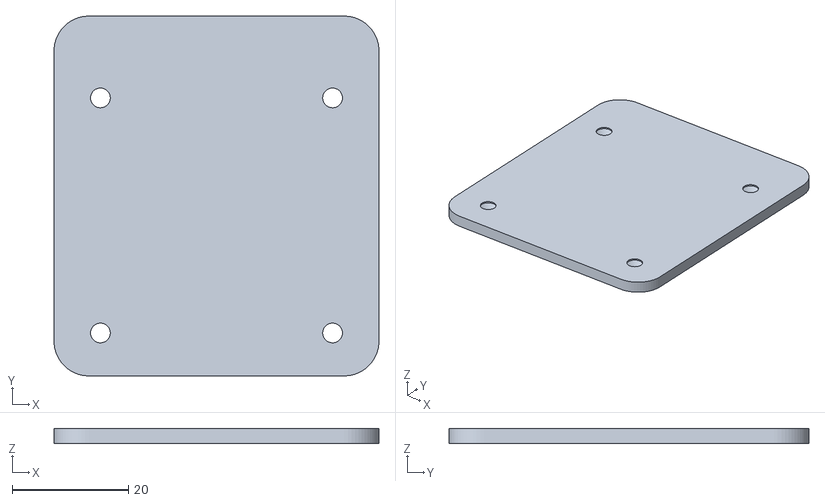
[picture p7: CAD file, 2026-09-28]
cad/stl/rotodamper_fan_cover.stl
56.0 x 62.0 x 2.50

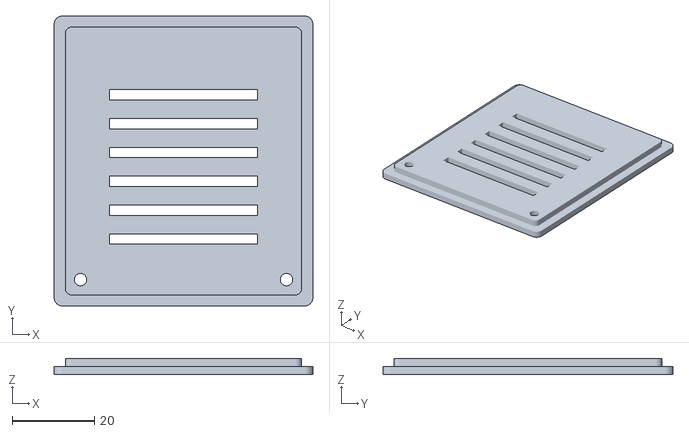
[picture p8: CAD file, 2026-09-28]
cad/stl/electronics_lid.stl
62.8 x 70.4 x 4.00

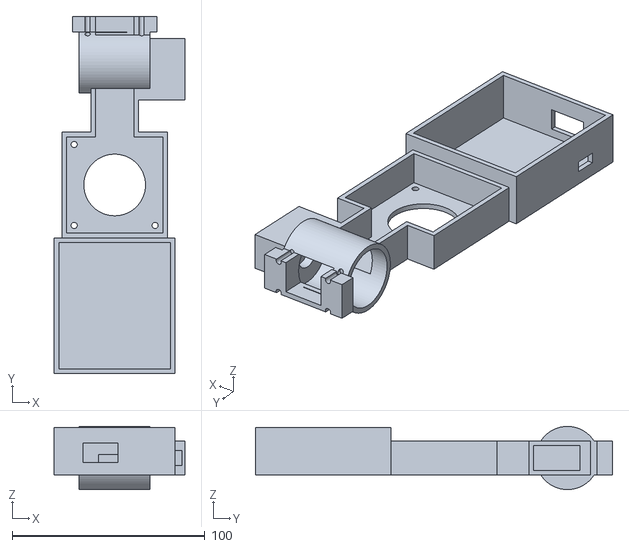
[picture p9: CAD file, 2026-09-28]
cad/stl/smoker_housing.stl
67.8 x 185.2 x 32.8

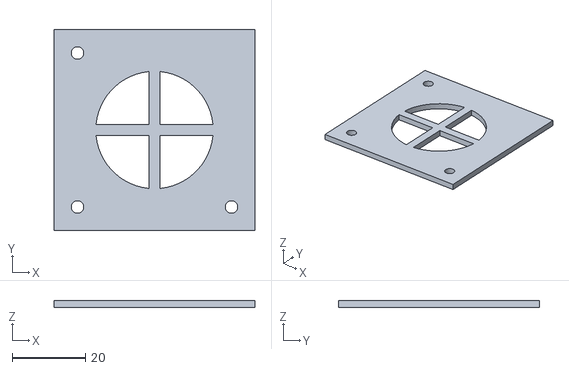
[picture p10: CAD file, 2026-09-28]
cad/stl/fan_cover.stl
54.8 x 54.8 x 2.00

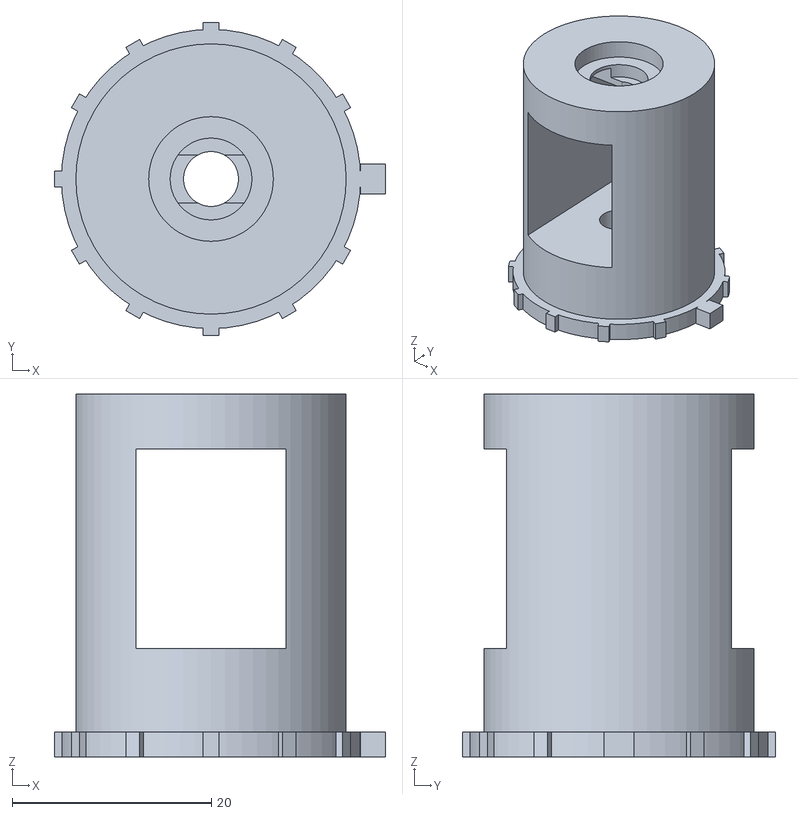
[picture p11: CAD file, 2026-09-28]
cad/stl/damper_rotor.stl
33.2 x 31.4 x 36.4

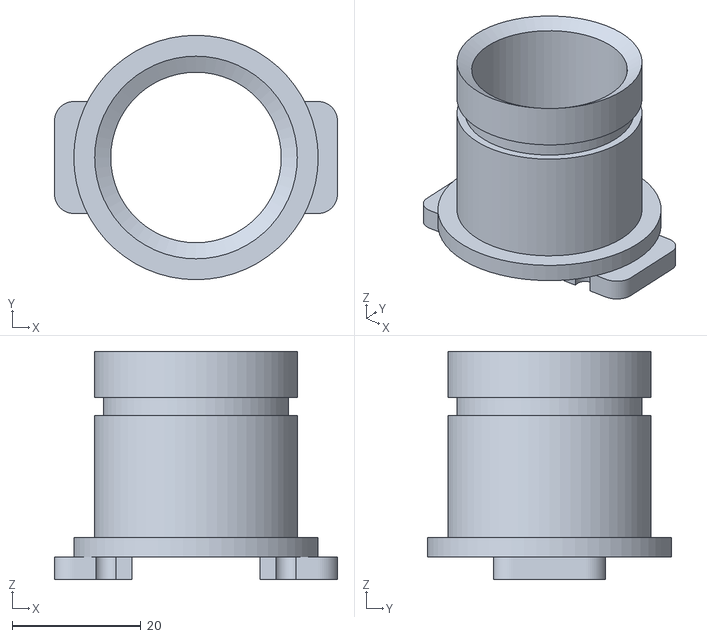
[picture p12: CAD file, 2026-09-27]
cad/stl/bbq_guru_vision_pro_nozzle_adapter.stl
44.0 x 38.0 x 35.5

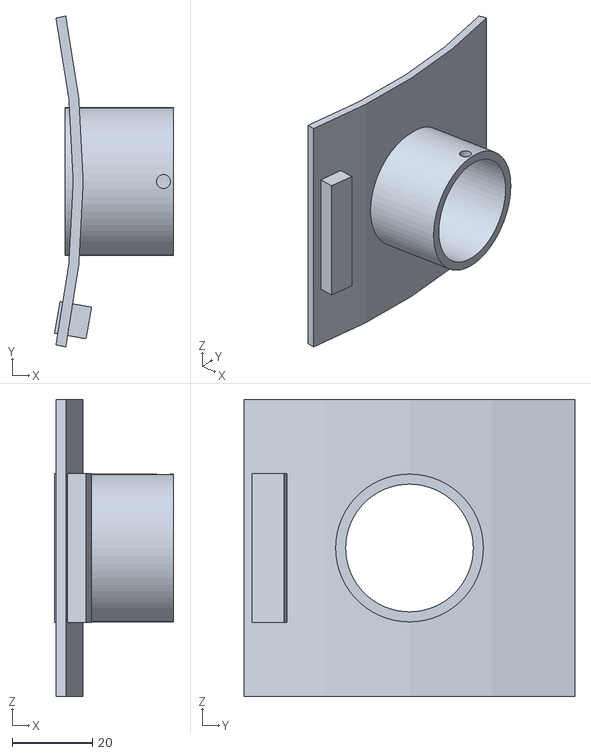
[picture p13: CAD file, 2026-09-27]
cad/stl/vision_pro_kamado_slide_plate.stl
29.7 x 82.4 x 74.0

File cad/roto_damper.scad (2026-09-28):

// =============================================================================
// ROTO-DAMPER (RD3 STYLE) BLOWER DAMPER SYSTEM
// =============================================================================
// High-performance rotary sector valve damper inspired by the HeaterMeter
// RD3 Roto-Damper architecture.
//
// Key Features:
// 1. Direct-Drive Coaxial MG90S Servo: Zero-backlash direct drive to damper disc.
// 2. 80-Degree Sector Aperture: 288.5 mm^2 open area matching the 5015 fan throat
//    (300 mm^2) for zero-restriction blower airflow, with a 10-degree solid overlap
//    barrier for 100% airtight closure against natural chimney drafts.
// 3. Integrated 5015 Blower Bay: Houses standard 50x50x15mm centrifugal blower.
// 4. Tethered RJ45 Umbilical Port: HeaterMeter-standard 8P8C interface connecting
//    to the external ESP32 controller / green perfboard circuit.
// 5. BBQ Guru Standard Nozzle: 31.5 mm OD with Dash-121 O-ring groove and 38 mm
//    stop collar, 100% compatible with vision_pro_kamado_slide_plate.stl.
//
// Render Options (pass via -D 'part="NAME"'):
//   part = "all"        - Full assembled view with color coding
//   part = "exploded"   - Exploded assembly view showing stackup
//   part = "base"       - Lower shell & lower plenum (STL export)
//   part = "disc"       - Rotary damper sector disc (STL export)
//   part = "cap"        - Upper plenum, nozzle, servo & RJ45 bay (STL export)
//   part = "fan_cover"  - Bottom intake grille & fan guard (STL export)
// =============================================================================

part = "all"; // ["all", "exploded", "base", "disc", "cap", "fan_cover"]
$fn = 60;

// -----------------------------------------------------------------------------
// DIMENSIONAL PARAMETERS
// -----------------------------------------------------------------------------
wall = 2.4;

// 5015 Blower Fan
fan_w = 50.5;
fan_l = 50.5;
fan_h = 15.5;
fan_intake_d = 33.0;

// Damper Disc
disc_d = 48.0;
disc_t = 2.5;
disc_clearance = 0.8;
chamber_id = disc_d + 2 * disc_clearance; // 49.6 mm

// Sector Aperture (80 degrees linear throttling)
sector_angle = 80;
sector_r_in = 7.0;
sector_r_out = 21.5;

// TowerPro MG90S Micro Servo
servo_w = 12.6;
servo_l = 23.2;
servo_h = 24.5;
servo_flange_l = 32.5;
servo_flange_w = 12.6;
servo_shaft_offset = 5.8; // Edge to output spline center

// BBQ Guru Output Nozzle
nozzle_od = 31.5;
nozzle_id = 26.5;
nozzle_len = 32.0;
stop_collar_od = 38.0;
stop_collar_w = 3.0;
oring_w = 2.8;
oring_depth = 1.4;
oring_dist = 14.0; // Distance from nozzle tip

// Housing Outer Profile
body_w = 56.0;
body_front_r = body_w / 2; // 28.0 mm
fan_bay_y = -76.0;
base_h = fan_h + wall + 2.5; // 20.4 mm (Z: -20.4 to 0)
cap_h = 22.0;                // Z: 0 to 22.0 mm

// -----------------------------------------------------------------------------
// HELPER MODULES
// -----------------------------------------------------------------------------

// 2D Outer Hull Profile
module hull_2d() {
    hull() {
        // Forward circular chamber centered at (0, 0)
        circle(r=body_front_r);
        // Rear rectangular fan bay with rounded corners
        translate([-body_w/2 + 6, fan_bay_y + 6]) circle(r=6);
        translate([body_w/2 - 6, fan_bay_y + 6]) circle(r=6);
        translate([-body_w/2 + 6, -20]) circle(r=6);
        translate([body_w/2 - 6, -20]) circle(r=6);
    }
}

// Symmetric Sector Port centered at +Y (90 degrees)
module sector_port(r_in, r_out, angle, h) {
    rotate([0, 0, 90 - angle/2])
        rotate_extrude(angle=angle)
        translate([r_in, 0])
        square([r_out - r_in, h]);
}

// -----------------------------------------------------------------------------
// 1. ROTARY DAMPER DISC (rotodamper_disc)
// -----------------------------------------------------------------------------
module rotodamper_disc() {
    difference() {
        union() {
            // Main disc body
            cylinder(d=disc_d, h=disc_t);

            // Raised low-friction sealing rim on bottom face
            translate([0, 0, -0.4])
                difference() {
                    cylinder(d=disc_d - 1.0, h=0.4);
                    translate([0, 0, -0.5])
                        cylinder(d=sector_r_in*2 - 1.0, h=1.4);
                }

            // Central hub boss for servo horn
            cylinder(d=12.5, h=disc_t + 2.2);

            // Tactile indicator tab aligned with aperture center (+Y)
            rotate([0, 0, 90])
                translate([disc_d/2 - 0.5, -1.5, 0])
                cube([3.0, 3.0, disc_t]);
        }

        // 80-degree sector aperture
        translate([0, 0, -1])
            sector_port(sector_r_in, sector_r_out, sector_angle, disc_t + 5);

        // MG90S servo horn recess
        translate([0, 0, disc_t + 2.2 - 2.2])
            cube([18.5, 4.8, 3.0], center=true);
        translate([0, 0, disc_t + 2.2 - 2.2])
            cylinder(d=8.2, h=3.0);

        // Center screw through-bore
        translate([0, 0, -2])
            cylinder(d=2.6, h=disc_t + 8);
    }
}

// -----------------------------------------------------------------------------
// 2. BASE HOUSING (rotodamper_base)
// -----------------------------------------------------------------------------
module rotodamper_base() {
    difference() {
        // Outer body extrusion
        translate([0, 0, -base_h])
            linear_extrude(height=base_h)
            hull_2d();

        // Disc recess on top face (Z = -disc_t - 0.3 to 0)
        translate([0, 0, -disc_t - 0.3])
            cylinder(d=chamber_id, h=disc_t + 1);

        // Fixed sector opening in divider floor
        translate([0, 0, -base_h - 1])
            sector_port(sector_r_in, sector_r_out, sector_angle, base_h + 2);

        // Lower plenum air chamber under disc
        translate([0, 0, -base_h + wall])
            cylinder(d=chamber_id - 6.0, h=base_h - wall - disc_t - 2.5);

        // 5015 Blower fan pocket
        translate([-fan_w/2, fan_bay_y + wall, -base_h + wall])
            cube([fan_w, fan_l, fan_h + 1]);

        // Airway manifold connecting fan throat to lower plenum
        translate([-15, -26, -base_h + wall])
            cube([30, 15, fan_h]);

        // Fan bottom air intake cutout
        translate([0, fan_bay_y + wall + fan_l/2, -base_h - 1])
            cylinder(d=fan_intake_d, h=wall + 2);

        // Internal wire pass-up channel from fan to rear RJ45 bay
        translate([body_w/2 - 7, -50, -base_h + wall])
            cube([4.0, 30.0, base_h]);

        // Disc center pivot screw pilot hole
        translate([0, 0, -base_h + wall])
            cylinder(d=2.8, h=base_h);

        // 4x M3 corner fastener holes for Cap assembly
        for (dx = [-1, 1]) {
            for (dy = [-1, 1]) {
                translate([dx * 22, (dy > 0 ? 16 : -66), -base_h - 1])
                    cylinder(d=2.8, h=base_h + 2);
            }
        }

        // 4x M3 screw pilot holes for bottom fan cover
        for (dx = [-1, 1]) {
            for (dy = [-1, 1]) {
                translate([dx * 20, fan_bay_y + wall + (dy > 0 ? fan_l - 5 : 5), -base_h - 1])
                    cylinder(d=2.8, h=8);
            }
        }
    }
}

// -----------------------------------------------------------------------------
// 3. CAP HOUSING (rotodamper_cap)
// -----------------------------------------------------------------------------
module rotodamper_cap() {
    difference() {
        union() {
            // Main cap body
            linear_extrude(height=cap_h)
                hull_2d();

            // BBQ Guru output nozzle at +Y (Z centered at 12 mm)
            translate([0, body_front_r - 2, 12])
                rotate([-90, 0, 0])
                union() {
                    cylinder(d=nozzle_od, h=nozzle_len);
                    cylinder(d=stop_collar_od, h=stop_collar_w);
                }
        }

        // Hollow nozzle bore
        translate([0, body_front_r - 5, 12])
            rotate([-90, 0, 0])
            cylinder(d=nozzle_id, h=nozzle_len + 10);

        // Dash-121 O-ring groove on nozzle
        translate([0, body_front_r - 2 + nozzle_len - oring_dist, 12])
            rotate([-90, 0, 0])
            difference() {
                cylinder(d=nozzle_od + 2, h=oring_w);
                translate([0, 0, -1])
                    cylinder(d=nozzle_od - 2*oring_depth, h=oring_w + 2);
            }

        // Upper plenum collecting chamber (over sector aperture)
        translate([0, 0, -1])
            intersection() {
                cylinder(d=chamber_id, h=14);
                translate([-body_w/2, 0, 0]) cube([body_w, body_front_r + 5, 16]);
            }

        // Funnel throat transition to nozzle bore
        translate([0, 10, 12])
            rotate([-90, 0, 0])
            cylinder(r1=15, r2=nozzle_id/2, h=16);
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

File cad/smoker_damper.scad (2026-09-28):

// ====================================================================
// ESP32 Smoker Fan & Servo Damper Controller
// Parametric 3D Printable Housing & Airflow Regulator (OpenSCAD)
// ====================================================================
// Supports:
//   - Configurable blower fan sizes (5015, 7530, 9733, etc.)
//   - Servo-driven rotating barrel damper (MG90S / SG90)
//   - Parametric output connection (Round pipe or Rectangular flange)
//   - Dual Form Factors:
//       * Config A: All-in-one integrated pod with ESP32 & 5V electronics bay
//       * Config B: Slim tethered pod with RJ45 umbilical connection
// ====================================================================

/* [Render Part Selection] */
// Which component to generate
part = "all"; // [all: Assembled Preview, housing: Main Housing Body, rotor: Damper Rotor, output_adapter: Smoker Output Adapter, vision_pro_plate: Vision Pro Kamado Slide Plate, lid: Electronics Bay Lid, fan_cover: Blower Intake Grille]

/* [Packaging Configuration] */
// True = All-in-one integrated pod (houses ESP32 + 5V circuitry); False = Slim tethered pod (RJ45 port)
include_electronics_bay = true;
// Main chassis wall thickness (mm)
wall = 2.4;

/* [Blower Fan Parameters] */
// Blower outer diameter / body width (mm) (e.g. 50 for 5015, 75 for 7530, 97 for 9733)
fan_size = 50; 
// Blower thickness / axial depth (mm) (e.g. 15 for 5015, 30 for 7530, 33 for 9733)
fan_depth = 15;
// Fan exhaust throat width (mm)
fan_throat_w = 20;
// Fan exhaust throat height (mm)
fan_throat_h = 15;
// Fan intake circle diameter (mm)
fan_intake_d = 32;

/* [Damper Valve & Servo Parameters] */
// Damper barrel cylinder outer diameter (mm)
damper_d = 28;
// Damper chamber length (mm)
damper_len = 32;
// Radial tolerance between rotor and housing walls (mm)
rotor_clearance = 0.45;
// Preview damper aperture angle in degrees (0 = Closed, 90 = Fully Open)
preview_angle = 45; // [0:90]

// Micro-servo dimensions (MG90S / SG90 default)
servo_w = 12.4;
servo_l = 23.0;
servo_h = 24.5;
servo_flange_l = 32.5;
servo_shaft_offset = 6.0;

// Derived Geometric Reference Coordinates
dc_x = (fan_size + 2*wall)/2; // Center X of blower & damper (27.4mm)
dc_y = fan_size + wall + 25 + damper_d/2; // Center Y of damper bore (91.4mm)
dc_z = (fan_depth + wall)/2; // Center Z of damper bore (8.7mm)

div_wall_inner_x = dc_x + damper_len/2; // Inner face of right dividing wall (43.4mm)
div_wall_outer_x = div_wall_inner_x + wall; // Outer face / servo mounting face (45.8mm)
sleeve_left_x = dc_x - (damper_len/2 + wall); // Left outer face of damper sleeve (9.0mm)

// Damper Rotor Dimensions
rotor_barrel_dia = damper_d - 2*rotor_clearance; // 27.1mm
rotor_flange_d = damper_d + 2.0; // 30.0mm (clears output boss at Y=106.8)
rotor_flange_t = 2.5;
rotor_len_left = (damper_len + 2*wall)/2; // 18.4mm (reaches from throat center to sleeve left face)
rotor_len_right = damper_len/2 - 0.5; // 15.5mm (leaves 0.5mm axial clearance at dividing wall)
rotor_barrel_len = rotor_len_left + rotor_len_right; // 33.9mm

/* [Smoker Output Connection] */
// Preset smoker interface adapter
output_preset = "bbq_guru"; // [bbq_guru: BBQ Guru Vision Pro / Pit Viper Port (1.25" / 31.5mm with O-Ring), custom_round: Custom Round Pipe, custom_rect: Custom Rectangular Duct, npt_1: 1" NPT Pipe (25.4mm), npt_1_5: 1.5" Pipe (38.1mm), kamado_rect: Kamado Slide Door]

// Nozzle cross-section geometry (derived from preset or manual)
output_shape = (output_preset == "custom_rect" || output_preset == "kamado_rect") ? "rectangular" : "round";

// Round output outer diameter (mm)
// Note: 31.5mm is sized with 0.25mm printing tolerance to slip snugly into BBQ Guru 31.8mm (1-1/4") receiver ports
output_round_od = (output_preset == "bbq_guru") ? 31.5 :
                  (output_preset == "npt_1") ? 25.4 :
                  (output_preset == "npt_1_5") ? 38.1 : 31.5;

// Round output wall thickness (mm)
output_round_wall = 2.5;

// Insertion nozzle length extending into smoker vent / adapter tube (mm)
output_nozzle_len = (output_preset == "bbq_guru") ? 32.0 : 35.0;

// Enable O-Ring friction seal groove on cylindrical nozzle (standard for BBQ Guru Pit Viper fit)
include_oring_groove = (output_preset == "bbq_guru");
// O-ring groove distance from nozzle tip (mm)
oring_offset_from_tip = 10.0;
// O-ring groove width (mm) (2.8mm accommodates standard 3/32" / 2.5mm cross-section O-rings)
oring_groove_width = 2.8;
// O-ring groove depth (mm) (1.4mm depth leaves 28.7mm root OD for standard Dash-121 / Dash-122 silicone O-rings)
oring_groove_depth = 1.4;

// Enable stop shoulder collar at base of nozzle (rests flush against BBQ Guru adapter face)
include_stop_collar = (output_preset == "bbq_guru");
// Stop collar outer diameter (mm)
stop_collar_d = 38.0;
// Stop collar thickness (mm)
stop_collar_t = 3.0;

// Rectangular output outer width (mm) (e.g. 50 for Kamado bottom slide vent)
output_rect_w = 50;
// Rectangular output outer height (mm)
output_rect_h = 30;
// Rectangular output wall thickness (mm)
output_rect_wall = 2.5;

// Enable mounting flange plate (with bolt holes for custom smoker mounting)
include_flange = (output_preset != "bbq_guru");
// Flange plate outer width (mm)
flange_w = 70;
// Flange plate outer height (mm)
flange_h = 55;
// Flange plate thickness (mm)
flange_t = 3.5;
// Flange screw hole diameter (mm)
flange_hole_d = 4.2;
// Flange hole horizontal center-to-center spacing (mm)
flange_hole_spacing_x = 55;
// Flange hole vertical center-to-center spacing (mm)
flange_hole_spacing_y = 40;

/* [Vision Pro S-Series Slide Plate (Drop-in Replacement)] */
// Width of Vision Kamado Pro S-Series draft track (mm)
vision_plate_w = 82.0;
// Height of Vision Kamado Pro S-Series draft door (mm)
vision_plate_h = 74.0;
// Plate thickness (mm)
vision_plate_t = 2.5;
// Ceramic kamado body radius of curvature (mm)
vision_kamado_r = 195.0;
// Female blower receiver port inner diameter (mm) (matches BBQ Guru 31.8mm / 1-1/4")
vision_port_id = 31.8;
// Female blower receiver port outer diameter (mm)
vision_port_od = 36.8;
// Female receiver port depth (mm)
vision_port_len = 25.0;

/* [Integrated Electronics Bay (Config A)] */
// Electronics bay interior width (mm) (fits ESP32 + MAX31855 + MOSFET PCB)
bay_interior_w = 58;
// Electronics bay interior length (mm)
bay_interior_l = 68;
// Electronics bay interior depth (mm)
bay_interior_h = 22;

/* [Rendering Quality] */
$fn = 60;

// ====================================================================
// HELPER MODULES & MATH
// ====================================================================

// Rounded box utility
module rounded_box(size, radius, sides=true) {
    w = size[0]; l = size[1]; h = size[2];
    hull() {
        translate([radius, radius, 0]) cylinder(r=radius, h=h);
        translate([w-radius, radius, 0]) cylinder(r=radius, h=h);
        translate([w-radius, l-radius, 0]) cylinder(r=radius, h=h);
        translate([radius, l-radius, 0]) cylinder(r=radius, h=h);
    }
}

// ====================================================================
// 1. MAIN HOUSING BODY
// ====================================================================
module main_housing() {
    difference() {
        union() {
            // Fan mounting pocket body
            translate([0, 0, 0])
                cube([fan_size + 2*wall, fan_size + 2*wall, fan_depth + wall]);

            // Transition duct to damper
            translate([(fan_size + 2*wall - fan_throat_w - 2*wall)/2, fan_size + wall - 1, 0])
                cube([fan_throat_w + 2*wall, 27, fan_depth + wall]);

            // Cylindrical damper housing sleeve
            translate([dc_x, dc_y, dc_z])
                rotate([0, 90, 0])
                cylinder(d=damper_d + 2*wall, h=damper_len + 2*wall, center=true);

            // Servo mounting bracket body
            translate([div_wall_outer_x, dc_y, 0])
                servo_bracket_body();

            // Output adapter mounting boss (modular 4-bolt flange face)
            translate([(fan_size + 2*wall - (damper_d + 16))/2, fan_size + wall + 25 + damper_d + wall - 1, 0])
                cube([damper_d + 16, 8, fan_depth + wall]);

            // Optional Integrated Electronics Bay (Config A)
            if (include_electronics_bay) {
                translate([(fan_size + 2*wall - bay_interior_w - 2*wall)/2, -bay_interior_l - wall, 0])
                    electronics_bay_body();
            } else {
                // Config B: RJ45 jack recess mount block
                translate([(fan_size + 2*wall - 22)/2, -12, 0])
                    cube([22, 12, fan_depth + wall]);
            }
        }

        // --- CUTOUTS ---

        // Blower fan pocket cutout
        translate([wall, wall, wall])
            cube([fan_size, fan_size, fan_depth + 1]);

        // Fan intake circular cutout on bottom
        translate([wall + fan_size/2, wall + fan_size/2, -1])
            cylinder(d=fan_intake_d, h=wall + 2);
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

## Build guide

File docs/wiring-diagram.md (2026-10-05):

# ESP32 Smoker Controller — Wiring Guide & Electrical Schematic

> Complete electrical reference, point-to-point connection tables, breadboard guide, and off-the-shelf module recommendations.
> **No custom printed circuit board (PCB) is required.** The system is designed to be assembled using standard off-the-shelf breakout boards, breadboards, or perfboards.

---

## 1. Quick Answer: Custom Circuit Board vs. Breadboard

* **Is a custom PCB required?**  
  **No.** You do not need to design or order a custom PCB.
* **Can it be built on a solderless breadboard?**  
  **Yes.** The entire circuit can be assembled and fully bench-tested on a standard half-size or full-size solderless breadboard using DuPont jumper wires.
* **How to package for the 3D printed housing?**  
  For final installation inside the 3D-printed pod (`cad/smoker_damper.scad`), you can either:
  1. **Build the Hobbyist Green Perfboard Layout (Recommended)**: Follow the complete step-by-step [Hobbyist Green Perfboard Circuit Board Layout & Assembly Guide](perfboard-assembly-guide.md), which provides a full coordinate grid layout, solder trace plan, and BOM for a standard $40\,\text{mm} \times 60\,\text{mm}$ ($4 \times 6\,\text{cm}$) board that drops directly into the electronics bay.
  2. Use common pre-built breakout modules (e.g. a $1 MOSFET breakout module, a MAX31855 breakout board, and an ESP32 DevKit).
  3. Solder the discrete components onto a compact prototype perfboard / stripboard.

---

## 2. Complete Schematic (Single 5V USB Rail)

```text
                                  +5V USB Power Source (Charger or Power Bank)
                                                |
          +-------------------------------------+---------------------------------------+
          |                                     |                                       |
          v                                     v                                       v
   [ 5V Blower Fan ]                     [ MG90S Servo ]                       [ ESP32 Dev Board ]
     (+) Red Lead                         (+) Red Lead                           (VIN / 5V Pin)
          |                                     |                                       |
     (-) Black Lead                             |                                       | (Internal LDO)
          |                                     |                                       v
          v Drain                               |                                  3.3V Bus
   +-------------+                              |                                       |
   |   N-MOSFET  |                              |        +---------------------+--------+---------------------+
   |  (AO3400A / |                              |        |                     |                              |
   |   IRLZ44N)  |                              |        v VCC                 v VCC                          v VCC
   +------+------+                              | [ MAX31855 Pit ]     [ MAX31855 Meat ]             [ Inland E-Ink Display ]
   Gate | | Source                              |   Breakout              Breakout                     (2.13" / 1.54" SPI)
        | +-----------+                         |        |                     |                              |
        |             |                         |        |                     |                              |
        |            GND                        |        |                     |                              |
        |             |                         |        |                     |                              |
        |             +-------------------------+--------+---------------------+------------------------------+
        |             |                         |                                                             |
        |             v (-)                     v (-)                                                         |
        |     +---------------+         +---------------+                                                     |
        |     | Flyback Diode |         | 1000uF Buffer |                                                     |
        |     | (1N5819 across|         | Electrolytic  |                                                     |
        |     | Fan + and -)  |         | Capacitor     |                                                     |
        |     +---------------+         +---------------+                                                     |
        |                                                                                                     |
        |                                                                                                     |
   150Ω | Gate Resistor                                                                                       |
   +----+--------------------------------- GPIO 25 (Blower PWM)                                               |
   |                                                                                                          |
 [100kΩ Pull-down to GND]                                                                                     |
                                          GPIO 26 (Servo PWM) ------------------------------------------------+
                                          (Direct to Servo Signal / Orange Wire)                              |
                                                                                                              |
                                          GPIO 18 (SPI SCK) ------------------ SCK (Shared Bus) --------------+
                                          GPIO 19 (SPI MISO) ----------------- SO (MAX31855 Shared) ----------+
                                          GPIO 23 (SPI MOSI) --------------------------------- DIN (E-Ink) ---+
                                          GPIO 5  (CS Pit) ------------------- CS (Pit Module only)           |
                                          GPIO 21 (CS Meat) ---------------------------------- CS (Meat only) |
                                          GPIO 4  (CS E-Ink) --------------------------------- CS (E-Ink) ----+
                                          GPIO 22 (DC E-Ink) --------------------------------- DC (E-Ink) ----+
                                          GPIO 16 (RST E-Ink) -------------------------------- RST (E-Ink) ---+
                                          GPIO 17 (BUSY E-Ink) ------------------------------- BUSY (E-Ink) --+
                                          GND -------------------------------- GND (Shared) ------------------+
```

---

## 3. Point-to-Point Pin Connection Table

### 3.1 Power Rail Connections (Single 5V USB Input)

| From (Source) | To (Destination) | Function | Notes |
| :--- | :--- | :--- | :--- |
| **USB 5V (+)** | ESP32 `VIN` / `5V` pin | System Logic Power | Powers ESP32 onboard 3.3V LDO regulator |
| **USB 5V (+)** | Blower Fan `(+)` Red Wire | Fan Power | Direct 5V power |
| **USB 5V (+)** | 1N5819 Diode Cathode (bar) | Inductive Snubber | Placed across fan terminals |
| **USB 5V (+)** | Servo Damper `(+)` Red Wire| Servo Power | 5V rail for MG90S |
| **USB 5V (+)** | 1000µF Cap `(+)` Lead | Brownout Buffer | Absorbs servo inrush currents |
| **USB GND (-)**| ESP32 `GND` pin | Common Ground | Reference ground |
| **USB GND (-)**| MOSFET `Source` Pin | Power Ground | Return path for fan |
| **USB GND (-)**| 100kΩ Resistor | Gate Pull-Down | Keeps fan OFF during boot |
| **USB GND (-)**| Servo Damper `(-)` Brown/Black Wire | Servo Ground | |
| **USB GND (-)**| 1000µF Cap `(-)` Lead | Capacitor Ground | |
| **USB GND (-)**| MAX31855 `GND` pins | Sensor Ground | Shared by both breakout boards |

---

### 3.2 Blower Fan Low-Side Switch Connections

| Component Pin | Connects To | Purpose |
| :--- | :--- | :--- |
| **ESP32 GPIO 25** | One side of $150\,\Omega$ resistor | LEDC PWM control output (25 kHz) |
| **$150\,\Omega$ resistor (other side)** | MOSFET `Gate` pin | Limits capacitive gate charge current |
| **$100\,\text{k}\Omega$ resistor** | Between MOSFET `Gate` and `GND` | Pull-down: prevents fan spinning during ESP32 boot |
| **MOSFET `Drain`** | Blower Fan `(-)` Black Wire + 1N5819 Anode | Switched return path |
| **MOSFET `Source`** | Common `GND` | Direct ground connection |
| **1N5819 Diode** | Across Fan `(+)` and `(-)` (Cathode to `+`, Anode to `-`) | Clamps inductive voltage spikes |

> **Pro Tip**: If using a pre-made MOSFET module (e.g. "LR7843 MOSFET module" or "IRF520 / D4184 module"), simply wire:
> - `SIG` to ESP32 `GPIO 25`
> - `GND` to ESP32 `GND`
> - `VIN + / -` to 5V power supply
> - `OUT + / -` to Blower Fan

---

### 3.3 Servo Damper Connections

| Component Pin | Connects To | Wire Color |
| :--- | :--- | :--- |
| **Servo Signal** | ESP32 `GPIO 26` | Orange wire (MG90S) / White wire |
| **Servo VCC (+)** | 5V USB Bus | Red wire |
| **Servo Ground (-)** | Common `GND` | Brown wire (MG90S) / Black wire |
| **1000µF 10V/16V Cap**| Across Servo VCC and GND | Electrolytic (Observe polarity: negative stripe to GND!) |

---

### 3.4 MAX31855 Thermocouple Breakout Connections

The MAX31855 runs on **3.3V logic**. Power both breakout modules from the ESP32 `3V3` pin.

| MAX31855 Pin | ESP32 Pin | Function | Notes |
| :--- | :--- | :--- | :--- |
| **VCC** | ESP32 `3V3` pin | 3.3V Logic Power | Do **NOT** connect to 5V! |
| **GND** | ESP32 `GND` pin | Common Ground | Shared |
| **SCK** (Clock) | ESP32 `GPIO 18` | SPI Clock | Shared by Pit and Meat modules |
| **SO / DO** (Data Out) | ESP32 `GPIO 19` | SPI MISO | Shared by Pit and Meat modules |
| **CS (Pit Module)** | ESP32 `GPIO 5` | Pit Chip Select | Dedicated to Pit sensor |
| **CS (Meat Module)**| ESP32 `GPIO 21`| Meat Chip Select | Dedicated to Meat sensor |

The default firmware enables only the pit converter. A food probe is optional; enable
its converter with `-D SMOKER_FOOD_CS=21` in the build flags. Missing food hardware
must not be reported as a valid food temperature or prevent healthy pit regulation.

For a MAX31856 K-type converter, build the `esp32dev-max31856` environment and also
connect its `SDI`/`MOSI` input to GPIO 23. SCK, SDO/MISO, and chip-select assignments
remain as above. Each enabled probe needs its own converter. The selected environment
configures the MAX31856 for K-type operation; the default environment uses MAX31855K.

---

### 3.5 Inland E-Ink Display Module Connections (2.13" or 1.54" SPI e-Paper)

The Inland E-Ink screen module (Micro Center) operates on **3.3V logic** and communicates over 4-wire SPI. It shares the hardware SPI clock (`SCK`) with the MAX31855 thermocouple amplifiers, but has its own dedicated Chip Select (`CS`) line.

> **Important**: Power the display from the ESP32 **`3V3`** pin. Do **NOT** connect VCC to the 5V rail, as excessive voltage can damage the e-paper driver IC.

| Inland Module Pin | Standard Jumper Color | ESP32 GPIO / Pin | Function | Notes |
| :--- | :--- | :--- | :--- | :--- |
| **VCC** | Red | ESP32 `3V3` pin | 3.3V Logic Power | Clean regulated 3.3V rail |
| **GND** | Black | ESP32 `GND` pin | Common Ground | System ground return |
| **DIN / MOSI** | Blue | ESP32 `GPIO 23` | SPI Data In (Master Out) | High-speed SPI data from ESP32 to display buffer |
| **CLK / SCK** | Yellow | ESP32 `GPIO 18` | SPI Clock | Shared clock line with MAX31855 amplifiers |
| **CS** | Orange | ESP32 `GPIO 4` | Chip Select (Active LOW) | Low enables E-Ink display communication |
| **DC** | Green | ESP32 `GPIO 22` | Data / Command Select | High = Display Data; Low = Command Register |
| **RST** | White | ESP32 `GPIO 16` | Hardware Reset (Active LOW) | Pulled low briefly on startup to reset display controller |
| **BUSY** | Purple | ESP32 `GPIO 17` | Busy Status (Active HIGH) | ESP32 polls this input to wait for refresh cycles to finish |

#### Shared-bus ownership
* **No Pin Contention**: The MAX31855 thermocouple chips are *read-only* SPI devices that transmit data to the ESP32 on `GPIO 19` (MISO). The Inland E-Ink display is a *write-only* device on `GPIO 23` (MOSI).
* **Independent Chip Selects**: When the ESP32 reads pit or food temperature, `GPIO 5` or `GPIO 21` is pulled LOW while `GPIO 4` (E-Ink CS) remains HIGH, so the display completely ignores the bus traffic. Conversely, during screen updates, only `GPIO 4` is pulled LOW.
* **Serialized SPI frames**: A shared bus owner acquires the bus before any chip-select assertion and releases it after deassertion. Separate data directions do not remove the need to serialize transactions. All three bus pins (SCK18, MISO19, MOSI23) are initialized once.
* **Task isolation**: Sensor sampling and control run on Core 1; network/display work runs on Core 0. Display busy waits occur outside bus ownership. SPI frame duration still contributes bounded scheduling latency; physical timing requires bench measurement.

---

## 4. Modular Tethered Setup: RJ45 Umbilical Pinout (Configuration B)

If you build **Configuration B** (microcontroller in a tabletop base unit with a Cat5/Cat6 network cable running to the damper pod on the smoker), wire the 8P8C (RJ45) jacks according to the community standard HeaterMeter pinout:

```text
                  RJ45 Female Socket (Front View / Tab Down)
                     +---+---+---+---+---+---+---+---+
                     | 1 | 2 | 3 | 4 | 5 | 6 | 7 | 8 |
                     +---+---+---+---+---+---+---+---+
```

| RJ45 Pin | T568B Wire Color | Connected Net | Purpose |
| :---: | :--- | :--- | :--- |
| **1** | White / Orange | *Unused / NC* | Reserved |
| **2** | Orange | *Unused / NC* | Reserved |
| **3** | White / Green | **+5V Servo Power** | Carries 5V to MG90S servo |
| **4** | Blue | **Common GND** | Shared ground return for fan and servo |
| **5** | White / Blue | **+5V Switched Fan** | Switched 5V from MOSFET in base box to Blower |
| **6** | Green | **Servo Signal** | 50Hz PWM signal from ESP32 GPIO 26 |
| **7** | White / Brown | *Unused / NC* | Reserved |
| **8** | Brown | *Unused / NC* | Reserved |

---

## 5. Recommended Off-the-Shelf Parts (BOM)

| Component | Recommended Model | Approx. Cost | Notes |
| :--- | :--- | :--- | :--- |
| **Microcontroller** | ESP32-WROOM-32D / DevKit V1 (30-pin or 38-pin) | ~$4.00 | Built-in Wi-Fi, Bluetooth, 3.3V LDO |
| **Chamber Probe Amp**| MAX31855 K-Type Thermocouple Breakout Board | ~$3.50 | SPI interface, cold-junction compensated |
| **Food Probe Amp** | MAX31855 Breakout Board (optional 2nd probe) | ~$3.50 | Shares SPI bus with pit probe |
| **E-Ink Screen** | Inland 2.13" or 1.54" SPI e-Paper Display Module | ~$7.99 – $9.99 | Micro Center Inland module (SSD1680 / UC8151D, daylight readable) |
| **Blower Fan** | 5V 5015 or 7530 DC Radial Blower Fan | ~$4.00 | Standard 50mm x 15mm or 75mm x 30mm centrifugal fan |
| **Damper Servo** | TowerPro MG90S (Metal Gear) Micro-Servo | ~$3.00 | High-torque metal gears withstand heat better than SG90 |
| **MOSFET Module** | LR7843, AO3400A, or IRLZ44N Breakout | ~$1.00 | Logic-level N-channel ($V_{GS} \le 3.3\text{V}$) |
| **Capacitor** | 1000µF 10V or 16V Radial Electrolytic Capacitor | ~$0.20 | Critical: suppresses servo stall brownouts |
| **Resistors** | $150\,\Omega$ and $100\,\text{k}\Omega$ 1/4W resistors | ~$0.10 | Gate damping and pull-down |
| **Diode** | 1N5819 Schottky or 1N4001 Rectifier Diode | ~$0.10 | Flyback protection |
| **Thermocouple** | Stainless braided K-type probe (pit and meat) | ~$4.00 | Rated up to 800°F (400°C) |

**Total Estimated Hardware Cost: ~$28.00 – $35.00**

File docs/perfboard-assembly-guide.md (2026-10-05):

# Hobbyist Green Perfboard Circuit Board Layout & Assembly Guide

> Step-by-step assembly manual, coordinate grid schedule, and solder trace layout for building the ESP32 Smoker Controller on a standard $40\,\text{mm} \times 60\,\text{mm}$ ($4 \times 6\,\text{cm}$) double-sided green prototyping board (perfboard).

---

## 1. Visual Circuit Board Layout Diagram

The technical diagram below illustrates both the **Top View** (component placement, sockets, and terminals) and the **Bottom View (X-Ray)** (solder bridges, copper bus wire, and insulated jumper routes):

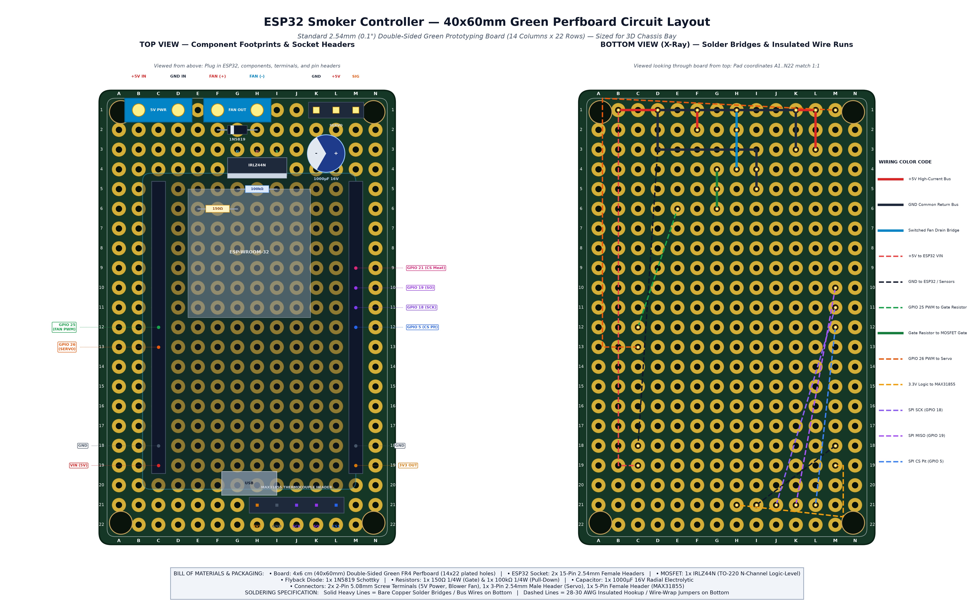
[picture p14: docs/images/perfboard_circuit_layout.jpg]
Green Perfboard Circuit Layout


---

## 2. Overview & Design Rationale

* **Direct Chassis Fit**: Standard double-sided green FR4 prototype boards ($40\,\text{mm} \times 60\,\text{mm}$, with 14 columns $\times$ 22 rows of $2.54\,\text{mm}$ / $0.1''$ pitch plated through-holes) drop directly into the rear electronics bay of the 3D-printed housing ([`cad/smoker_damper.scad`](../cad/smoker_damper.scad)).
* **Socketed ESP32**: The ESP32 DevKit is mounted using two 15-pin female socket headers rather than being soldered permanently, allowing easy removal for bench testing or firmware re-flashing.
* **Separation of Power & Sensors**:
  * **Top Section (Rows 1–6)**: Houses all high-current 5V power routing (USB power terminal, blower fan screw terminal, MOSFET low-side switch, flyback diode, servo header, and 1000µF brownout buffer capacitor).
  * **Middle Section (Rows 5–19)**: ESP32 DevKit socket headers with low-profile gate resistors tucked underneath.
  * **Bottom Section (Rows 20–22)**: 3.3V logic and SPI bus headers for the MAX31855 thermocouple amplifier module, facing the end-wall thermocouple port.

---

## 3. Bill of Materials (BOM)

| Reference | Component | Package / Footprint | Rating / Specification | Notes |
| :--- | :--- | :--- | :--- | :--- |
| **PCB** | Prototyping Perfboard | $40\,\text{mm} \times 60\,\text{mm}$ ($4\times 6\,\text{cm}$) | Double-sided FR4, $2.54\,\text{mm}$ ($0.1''$) pitch, 14 cols $\times$ 22 rows | Ubiquitous green board (Elegoo, Smraza, generic Amazon/AliExpress) |
| **U1 Sockets** | ESP32 DevKit Sockets | 2x 15-pin Female Headers | $2.54\,\text{mm}$ pitch, single row ($8.5\,\text{mm}$ plastic height) | Accepts 30-pin ESP32 DevKit v1 |
| **Q1** | N-Channel MOSFET | TO-220 Through-Hole | **IRLZ44N** or **FQP30N06L** ($V_{\text{GS(th)}} \le 2.0\,\text{V}$, Logic-Level) | Controls 5015 blower fan ground path |
| **D1** | Flyback Snubber Diode | DO-41 Axial Through-Hole | **1N5819** Schottky ($40\,\text{V}, 1\,\text{A}$) | Clamps inductive motor voltage spikes |
| **C1** | Buffer Capacitor | Radial Can Through-Hole | **$1000\,\mu\text{F}$ 16V** Electrolytic ($8\text{--}10\,\text{mm}$ dia, $5\,\text{mm}$ pitch) | Absorbs servo inrush currents; prevents ESP32 brownouts |
| **R1** | Gate Resistor | Axial 1/4W Resistor | **$150\,\Omega$** (Brown-Green-Brown-Gold) | Limits ESP32 GPIO 25 gate charging surge current |
| **R2** | Gate Pull-Down Resistor| Axial 1/4W Resistor | **$100\,\text{k}\Omega$** (Brown-Black-Yellow-Gold) | Holds Gate low during boot so fan stays OFF |
| **J1** | 5V Power Input | 2-Pin Screw Terminal Block | $5.08\,\text{mm}$ pitch (blue or green block) | Pin 1 = `+5V`, Pin 2 = `GND` |
| **J2** | Blower Fan Output | 2-Pin Screw Terminal Block | $5.08\,\text{mm}$ pitch (blue or green block) | Pin 1 = `+5V FAN`, Pin 2 = `Switched DRAIN` |
| **J3** | Servo Damper Header | 3-Pin Male Header | $2.54\,\text{mm}$ pitch, straight pins | Pin 1 = `GND`, Pin 2 = `+5V`, Pin 3 = `SIG` |
| **J4** | Thermocouple Header | 5-Pin Female Header | $2.54\,\text{mm}$ pitch, straight socket | Accepts MAX31855 breakout board (3V3, GND, SCK, SO, CS) |
| **W1–W8** | Hookup Wire | 28–30 AWG Insulated | Flexible silicone or Kynar wire-wrap | Bottom-side signal runs |

---

## 4. Grid Coordinate Pinout Schedule

Coordinates follow standard battleship grid notation: **Columns A through N** ($X = 1 \dots 14$) from left to right, and **Rows 1 through 22** ($Y = 1 \dots 22$) from top to bottom.

### 4.1 Component Placement (Top Side)

| Component | Lead / Pin | Grid Hole (Col, Row) | Net / Connection |
| :--- | :--- | :---: | :--- |
| **J1 (5V Power Terminal)** | Pin 1 (`+5V IN`) | **(B, 1)** | Connects to +5V high-current bus |
| | Pin 2 (`GND IN`) | **(D, 1)** | Connects to common ground bus |
| **J2 (Fan Output Terminal)**| Pin 1 (`+5V FAN`) | **(F, 1)** | Connects to +5V high-current bus & D1 Cathode |
| | Pin 2 (`DRAIN (-)`) | **(H, 1)** | Connects to Q1 Drain & D1 Anode |
| **J3 (Servo Header)** | Pin 1 (`GND`) | **(K, 1)** | Connects to common ground bus & C1 (-) lead |
| | Pin 2 (`+5V`) | **(L, 1)** | Connects to +5V high-current bus & C1 (+) lead |
| | Pin 3 (`SIG`) | **(M, 1)** | Connects to ESP32 GPIO 26 |
| **D1 (1N5819 Diode)** | Cathode (silver bar) | **(F, 2)** | Solder-bridged to (F, 1) (`+5V`) |
| | Anode | **(H, 2)** | Solder-bridged to (H, 1) (`DRAIN`) |
| **C1 (1000µF Capacitor)** | Negative Lead `(-)` | **(K, 3)** | Solder-bridged to (K, 1) (`GND`) |
| | Positive Lead `(+)` | **(L, 3)** | Solder-bridged to (L, 1) (`+5V`) |
| **Q1 (IRLZ44N MOSFET)** | Pin 1: Gate (G) | **(G, 4)** | Connects to R1 ($150\,\Omega$) & R2 ($100\,\text{k}\Omega$) |
| | Pin 2: Drain (D) | **(H, 4)** | Solder-bridged to (H, 2) and (H, 1) |
| | Pin 3: Source (S) | **(I, 4)** | Solder-bridged to common ground bus |
| **R2 (100kΩ Resistor)** | Lead 1 | **(G, 5)** | Solder-bridged to (G, 4) (Gate) |
| | Lead 2 | **(I, 5)** | Solder-bridged to (I, 4) (Source / GND) |
| **R1 (150Ω Resistor)** | Lead 1 (Input) | **(E, 6)** | Connects to ESP32 GPIO 25 via jumper wire |
| | Lead 2 (Output) | **(G, 6)** | Solder-bridged to (G, 5) and (G, 4) (Gate) |
| **U1-Left (ESP32 Socket)** | Pins 1–15 | **(C, 5) to (C, 19)** | Left socket header (accepts pins EN through VIN) |
| **U1-Right (ESP32 Socket)**| Pins 16–30 | **(M, 5) to (M, 19)**| Right socket header (accepts pins 3V3 through D23) |
| **J4 (MAX31855 Header)** | Pin 1 (`3V3`) | **(H, 21)** | Connects to ESP32 3V3 output at (M, 19) |
| | Pin 2 (`GND`) | **(I, 21)** | Connects to common ground bus |
| | Pin 3 (`SCK`) | **(J, 21)** | Connects to ESP32 GPIO 18 at (M, 11) |
| | Pin 4 (`SO / MISO`) | **(K, 21)** | Connects to ESP32 GPIO 19 at (M, 10) |
| | Pin 5 (`CS Pit`) | **(L, 21)** | Connects to ESP32 GPIO 5 at (M, 12) |

---

## 5. Step-by-Step Soldering Sequence

Follow this assembly order to ensure easy mechanical access and avoid trapping wires under larger parts:

```mermaid
flowchart TD
    Step1["Phase 1: Sockets & Passive Components\n(Headers, Resistors, Diode)"] --> Step2["Phase 2: High-Current Solder Buses\n(+5V Bus & GND Bus on Bottom)"]
    Step2 --> Step3["Phase 3: Power Semiconductor & Cap\n(MOSFET IRLZ44N & 1000uF Buffer)"]
    Step3 --> Step4["Phase 4: Screw Terminals & Servo Header\n(J1 5V In, J2 Fan Out, J3 Servo)"]
    Step4 --> Step5["Phase 5: Insulated Signal Jumpers\n(PWM lines, SPI bus, 3.3V sensor rail)"]
    Step5 --> Step6["Phase 6: Cold Pre-Flight Multimeter Audit\n(Zero-voltage continuity & short-circuit check)"]
```

### Phase 1: Low-Profile Components & Sockets
1. Insert the two 15-pin female socket headers at **(C, 5..19)** and **(M, 5..19)**. Secure with tape, flip the board, and solder corner pins first to align flush.
2. Insert the $150\,\Omega$ gate resistor across **(E, 6)** and **(G, 6)**. Solder on bottom and trim excess leads.
3. Insert the $100\,\text{k}\Omega$ pull-down resistor across **(G, 5)** and **(I, 5)**. Solder on bottom and trim.
4. Insert the 1N5819 Schottky diode across **(F, 2)** and **(H, 2)** with the **silver cathode band facing (F, 2)**.

### Phase 2: High-Current Solder Buses & Bridges
Use bent component leads or bare 20–22 AWG solid tinned copper wire:
1. **+5V Main Rail**: Run a solid wire from **(B, 1)** $\rightarrow$ **(F, 1)** $\rightarrow$ **(L, 1)**.
   * Solder-bridge **(F, 1)** to diode cathode at **(F, 2)**.
   * Solder-bridge **(L, 1)** to capacitor positive pad at **(L, 3)**.
2. **Ground Main Rail**: Run a solid wire from **(D, 1)** $\rightarrow$ **(D, 3)** $\rightarrow$ **(I, 3)** $\rightarrow$ **(I, 4)** $\rightarrow$ **(I, 5)**.
   * Bridge to servo ground at **(K, 1)** $\rightarrow$ **(K, 3)**.
3. **Switched Fan Drain Bridge**: Create a continuous 3-pad solder bridge from **(H, 1)** (Fan -) down through **(H, 2)** (Diode Anode) to **(H, 4)** (MOSFET Drain).
4. **Gate Node Bridge**: Create a continuous 3-pad solder bridge from **(G, 6)** ($150\,\Omega$ out) through **(G, 5)** ($100\,\text{k}\Omega$) to **(G, 4)** (MOSFET Gate).

### Phase 3: Power Semiconductor & Buffer Capacitor
1. **MOSFET (Q1)**: Insert the IRLZ44N into **(G, 4)** [Gate], **(H, 4)** [Drain], and **(I, 4)** [Source]. The metal tab should face toward Row 5. Solder in place.
2. **Capacitor (C1)**: Insert the $1000\,\mu\text{F}$ capacitor into **(K, 3)** [Negative Lead `(-)`] and **(L, 3)** [Positive Lead `(+)`]. Observe the white/grey stripe on the body indicating the negative lead! Solder and trim.

### Phase 4: External Connectors
1. Insert the 5V Power screw terminal at **(B, 1)** and **(D, 1)** (wire entry facing top edge).
2. Insert the Blower Fan screw terminal at **(F, 1)** and **(H, 1)**.
3. Insert the 3-pin male servo header at **(K, 1)**, **(L, 1)**, and **(M, 1)**.
4. Insert the 5-pin female MAX31855 header at **(H, 21)** through **(L, 21)**.

### Phase 5: Point-to-Point Insulated Signal Jumpers
Run thin insulated wire (28–30 AWG Kynar or silicone hookup wire) on the bottom layer:
1. **+5V to ESP32**: Jumper from **(B, 1)** to ESP32 `VIN` at **(C, 19)**.
2. **GND to ESP32**: Jumper from **(D, 3)** to ESP32 `GND` at **(C, 18)**.
3. **Fan PWM**: Jumper from ESP32 `GPIO 25` at **(C, 12)** to $150\,\Omega$ input at **(E, 6)**.
4. **Servo PWM**: Jumper from ESP32 `GPIO 26` at **(C, 13)** along outer border up to Servo Signal at **(M, 1)**.
5. **3.3V Sensor Power**: Jumper from ESP32 `3V3` at **(M, 19)** to MAX31855 `VCC` at **(H, 21)**.
6. **Sensor Ground**: Jumper from ESP32 `GND` at **(M, 18)** to MAX31855 `GND` at **(I, 21)**.
7. **SPI SCK**: Jumper from ESP32 `GPIO 18` at **(M, 11)** to MAX31855 `SCK` at **(J, 21)**.
8. **SPI SO (MISO)**: Jumper from ESP32 `GPIO 19` at **(M, 10)** to MAX31855 `SO` at **(K, 21)**.
9. **SPI CS Pit**: Jumper from ESP32 `GPIO 5` at **(M, 12)** to MAX31855 `CS` at **(L, 21)**.

### Phase 5.1: Optional Inland E-Ink Screen Harness (Lid-Mounted)
If installing an Inland 2.13" or 1.54" e-Paper display in the electronics lid, run an 8-wire ribbon cable or DuPont harness from the following ESP32 socket pins:

| E-Ink Header Pin | ESP32 Board Pin | Grid Coord | Function |
| :--- | :--- | :---: | :--- |
| **1. VCC** | `3V3` | **(M, 19)** | 3.3V Logic Supply |
| **2. GND** | `GND` | **(M, 18)** | Common Ground |
| **3. DIN / MOSI**| `GPIO 23` | **(M, 5)** | Master-Out-Slave-In |
| **4. CLK / SCK** | `GPIO 18` | **(M, 11)** | SPI Clock (shared with MAX31855) |
| **5. CS** | `GPIO 4` | **(C, 16)** | E-Ink Chip Select |
| **6. DC** | `GPIO 22` | **(M, 6)** | Data / Command Select |
| **7. RST** | `GPIO 16` | **(C, 14)** | Hardware Reset |
| **8. BUSY** | `GPIO 17` | **(C, 15)** | Busy Status |

---

## 6. Pre-Flight Multimeter Inspection (Do NOT plug in ESP32 yet!)

Perform these electrical safety checks with a Digital Multimeter (DMM) set to **Continuity / Resistance Mode** before applying power:

| Check # | Test Points | Expected Reading | Fault Condition & Cause |
| :---: | :--- | :---: | :--- |
| **1** | Power Terminal `+5V` (B1) to `GND` (D1) | **Open Circuit / High Resistance** ($> 10\,\text{k}\Omega$) | If $< 100\,\Omega$ or beeping: **DEAD SHORT** on 5V bus! Check capacitor polarity and solder blobs. |
| **2** | ESP32 Socket `VIN` (C19) to Power `+5V` (B1) | **$0.0\,\Omega$ (Direct Continuity)** | If open: Check Phase 5 Jumper #1. |
| **3** | ESP32 Socket `GND` (C18 & M18) to Power `GND` (D1) | **$0.0\,\Omega$ (Direct Continuity)** | If open: Check Phase 5 Jumper #2. |
| **4** | Fan Output `+5V` (F1) to Power `+5V` (B1) | **$0.0\,\Omega$ (Direct Continuity)** | If open: Check top rail copper bus. |
| **5** | MOSFET Drain (H4) to Fan Output `DRAIN` (H1) | **$0.0\,\Omega$ (Direct Continuity)** | If open: Check 3-pad solder bridge. |
| **6** | MOSFET Gate (G4) to Ground (I4) | **$100.0\,\text{k}\Omega \pm 5\%$** | Verifies pull-down resistor integrity. |
| **7** | ESP32 `GPIO 25` (C12) to MOSFET Gate (G4) | **$150.0\,\Omega \pm 5\%$** | Verifies gate protection resistor connection. |
| **8** | ESP32 `GPIO 26` (C13) to Servo Signal (M1) | **$0.0\,\Omega$ (Direct Continuity)** | If open: Check servo PWM jumper. |
| **9** | ESP32 `3V3` (M19) to MAX31855 `VCC` (H21) | **$0.0\,\Omega$ (Direct Continuity)** | Verifies sensor power rail. |
| **10** | D1 Diode Test Mode (F2 to H2) | **$0.25\text{--}0.45\,\text{V}$ forward drop** (Cathode at F2) | If $0.0\,\text{V}$: Diode shorted; if inverted: Diode backwards! |

---

## 7. Power-Up & Bench Testing Procedure

1. **Step 1: First Power-On (Without ESP32)**
   * Connect a 5V USB-C or bench power supply to the 5V Power Terminal `(B1, D1)`.
   * Measure voltage with DMM across socket pins:
     * Pin `(C19)` (`VIN`) to `(C18)` (`GND`): Must read **$4.9\text{--}5.2\,\text{V}$ DC**.
     * Fan terminal `(F1)` to `(D1)`: Must read **$5.0\,\text{V}$ DC**.
     * Fan terminal `(H1)` (Drain): Must float high or show no return to ground.
2. **Step 2: Insert ESP32**
   * Disconnect power.
   * Firmly seat the ESP32 DevKit into socket headers `(C5..19)` and `(M5..19)` with the micro-USB port oriented toward Row 20 (bottom).
   * Reconnect 5V power. Verify the red power LED on the ESP32 illuminates.
3. **Step 3: Connect Blower Fan & Servo**
   * Wire the 5015 blower fan red lead to `(F1)` and black lead to `(H1)`.
   * Plug the MG90S servo into header `(K1..M1)` with the brown ground wire to `K1`.
   * Power on the controller. The fan should remain **completely silent and stopped** during boot.
   * Through the Web UI or serial console, send a command to set fan speed to 50%:
     * Blower fan should spin up smoothly at 25 kHz PWM.
     * Set servo angle to $90^\circ$: Servo should rotate cleanly without causing brownouts or rebooting the ESP32.
4. **Step 4: Thermocouple Verification**
   * Plug the MAX31855 breakout module into header `(H21..L21)`.
   * Connect K-Type thermocouple probe to the screw terminal.
   * The web interface should immediately report ambient room temperature (e.g. $72^\circ\text{F} / 22^\circ\text{C}$).
   * Warm the probe tip with your fingers to observe responsive temperature rise.

---

## 8. Installation into 3D Enclosure (`cad/smoker_damper.scad`)

1. Slide the assembled green perfboard into the rear bay of [`smoker_housing.stl`](../cad/stl/smoker_housing.stl).
2. The top edge (Row 1) faces the divider wall: fan and servo wires pass cleanly through the divider cutout.
3. The bottom edge (Row 22) faces the rear wall: thermocouple probe wires exit directly through the end-wall slot.
4. Align [`electronics_lid.stl`](../cad/stl/electronics_lid.stl) over the bay and secure with two M3x6mm screws.

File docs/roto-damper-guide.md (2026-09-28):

# Roto-Damper (RD3 Style) Damper System — Technical Guide

This guide details **Design 2: Roto-Damper (RD3 Style)**, a compact 4-piece rotary sector valve blower system inspired by the HeaterMeter RD3 community architecture. It includes full mechanical specifications, 3D printing parameters, exploded assembly instructions, electrical umbilical pinouts, and a side-by-side comparison with **Design 1: Integrated Barrel Damper Pod**.

---

## 1. System Overview & Architecture

Roto-Damper Exploded Assembly Diagram

The **Roto-Damper** design decouples the blower/damper hardware at the smoker draft vent from the main microcontroller electronics. Instead of an onboard microcontroller bay, it uses a **tethered RJ45 umbilical interface** (standard Cat5/Cat6 8P8C) connecting back to the external ESP32 controller / [Green Perfboard Circuit Layout](perfboard-assembly-guide.md).

### Core Architectural Features

1. **Direct Coaxial Servo Drive**:
   - The TowerPro MG90S metal-gear micro-servo is mounted inverted directly above the central axis of the damper disc.
   - Its output spline engages the disc hub pocket with zero linkages, gears, or bellcranks, eliminating all mechanical backlash.
2. **80-Degree Sector Aperture Valve**:
   - An $80^\circ$ radial sector opening ($r_{in} = 7.0\,\text{mm}$, $r_{out} = 21.5\,\text{mm}$) provides an unobstructed flow area of **$288.5\,\text{mm}^2$**, matching the $20 \times 15\,\text{mm} = 300\,\text{mm}^2$ exhaust throat of a 5015 centrifugal blower fan (96.2% parity).
   - At $90^\circ$ closed rotation, the solid plate covers the fixed base port with a **$10^\circ$ solid safety overlap margin**, creating a 100% hermetic seal against natural chimney drafting.
3. **Plenum Equalization Chamber**:
   - The fan exhaust discharges into a lower circular plenum chamber ($43.6\,\text{mm}$ ID $\times 13.0\,\text{mm}$ H) where dynamic air pressure converts to uniform static pressure before passing upward through the sector valve into the upper collecting plenum.
4. **BBQ Guru Standard Output Nozzle**:
   - An integral $31.5\,\text{mm}$ OD output nozzle ($26.5\,\text{mm}$ ID, $32.0\,\text{mm}$ insertion length) with a Dash-121 silicone O-ring groove and $38.0\,\text{mm}$ mechanical stop collar slides directly into [`vision_pro_kamado_slide_plate.stl`](../cad/stl/vision_pro_kamado_slide_plate.stl).
5. **Ergonomic Clam-Shell Puck**:
   - Compact footprint ($56\,\text{mm}$ width $\times 104\,\text{mm}$ length $\times 42.4\,\text{mm}$ total assembled height).

---

## 2. Bill of Materials (BOM)

### 3D Printed Components (`cad/stl/`)

| Part Filename | Qty | Recommended Material | Print Infill / Walls | Function / Description |
| :--- | :---: | :--- | :--- | :--- |
| [`rotodamper_base.stl`](../cad/stl/rotodamper_base.stl) | 1 | PETG / ABS / ASA | 4 perimeters, 35% infill | Lower clam shell, 5015 fan bay, static lower plenum, divider deck with fixed $80^\circ$ sector port, disc bearing seat |
| [`rotodamper_disc.stl`](../cad/stl/rotodamper_disc.stl) | 1 | PETG / ABS / ASA | 4 perimeters, 100% solid | Rotary sector damper disc ($48.0\,\text{mm}$ OD $\times 2.5\,\text{mm}$ T), raised low-friction sealing land, MG90S horn pocket, position tab |
| [`rotodamper_cap.stl`](../cad/stl/rotodamper_cap.stl) | 1 | PETG / ABS / ASA | 4 perimeters, 35% infill | Upper clam shell, upper plenum collecting chamber, $31.5\,\text{mm}$ BBQ Guru nozzle, MG90S servo mount, RJ45 umbilical bay |
| [`rotodamper_fan_cover.stl`](../cad/stl/rotodamper_fan_cover.stl) | 1 | PETG / ABS / ASA | 3 perimeters, 30% infill | Bottom protective plate with aerodynamic intake louvers and wire notch |
| [`vision_pro_kamado_slide_plate.stl`](../cad/stl/vision_pro_kamado_slide_plate.stl) | 1 | PETG / ABS / ASA | 5 perimeters, 40% infill | Curved slide plate dropping into Vision Kamado Pro S-Series draft door track with $31.8\,\text{mm}$ female receiver port |

### Hardware & Fasteners

| Item | Qty | Specification | Purpose |
| :--- | :---: | :--- | :--- |
| **5015 Blower Fan** | 1 | 12V DC Brushless Radial Blower ($50 \times 50 \times 15\,\text{mm}$), 4.5–5.5 CFM | Stoking combustion air |
| **Micro Servo** | 1 | TowerPro MG90S Metal-Gear Micro Servo ($9\text{g}$, 4.8V–6.0V, 1.8–2.2 kg·cm) | Proportional throttling damper disc |
| **RJ45 Keystone / Socket** | 1 | 8P8C Female RJ45 PCB Breakout / Keystone Jack | Umbilical cable connection |
| **O-Ring** | 1 | Dash-121 High-Temp Silicone or Viton ($26.65\,\text{mm}$ ID $\times 2.38\,\text{mm}$ CS) | Hermetic friction seal into slide plate |
| **Main Clamp Screws** | 4 | M3 $\times 25\,\text{mm}$ Socket Head Cap Screws (304 Stainless) | Clamping Cap to Base |
| **Threaded Inserts** | 4 | M3 Brass Heat-Set Inserts ($\varnothing 4.2\,\text{mm} \times 5.0\,\text{mm}$ L) or direct M3 tap | Base corner fastener anchors |
| **Fan Cover Screws** | 4 | M3 $\times 8\,\text{mm}$ Countersunk Flat Head Screws | Securing bottom fan cover to base |
| **Disc Retaining Screw** | 1 | M2.5 or M3 $\times 8\,\text{mm}$ Pan Head Screw + Nylon Washer | Securing disc to base center pivot |
| **Servo Horn Screw** | 1 | M2 $\times 6\,\text{mm}$ Phillips Screw (included with servo) | Locking horn into MG90S brass spline |
| **Servo Mounting Screws**| 2 | M2 $\times 8\,\text{mm}$ Self-Tapping Screws (included with servo) | Fastening MG90S flange into Cap |

---

## 3. Electrical Umbilical Pinout (RJ45 Cat5/Cat6)

The Roto-Damper connects to the ESP32 controller / [Green Perfboard Circuit](perfboard-assembly-guide.md) via a standard Cat5e or Cat6 ethernet patch cable using the standard HeaterMeter/RD3 pinout:

```text
       RJ45 8P8C Female Socket (Rear of rotodamper_cap)
       +-----------------------------------------------+
       |  [1]   [2]   [3]   [4]   [5]   [6]   [7]   [8] |
       +---+-----+-----+-----+-----+-----+-----+-----+---+
           |     |     |     |     |     |     |     |
           |     |     |     |     |     |     |     +-- Spare / Ground
           |     |     |     |     |     |     +-------- Servo Ground (Black/Brown)
           |     |     |     |     |     +-------------- Servo PWM Signal (Orange/Yellow - GPIO 18)
           |     |     |     |     +-------------------- Servo +5V Power (Red)
           |     |     +-----+-------------------------- Fan 12V Switched Ground (MOSFET Drain - 2 Pins)
           +-----+-------------------------------------- Fan +12V DC Power (2 Pins for high current)
```

| RJ45 Pin | T568B Color | Signal Name | Connected Device | Voltage / Spec |
| :---: | :--- | :--- | :--- | :--- |
| **1** | White/Orange | **+12V_FAN** | 5015 Blower Fan (+) Red Wire | +12V DC (continuous bus) |
| **2** | Orange | **+12V_FAN** | 5015 Blower Fan (+) Red Wire | Paired for low resistance |
| **3** | White/Green | **FAN_DRAIN** | 5015 Blower Fan (-) Black Wire | Switched GND from IRLZ44N MOSFET Drain |
| **4** | Blue | **FAN_DRAIN** | 5015 Blower Fan (-) Black Wire | Paired for low resistance |
| **5** | White/Blue | **+5V_SERVO** | MG90S Servo (+) Red Wire | +5V DC Regulated |
| **6** | Green | **SERVO_PWM** | MG90S Servo Signal (Orange/Yellow) | 3.3V/5V PWM Signal from ESP32 GPIO 18 |
| **7** | White/Brown | **SERVO_GND** | MG90S Servo (-) Brown/Black Wire | Ground Reference |
| **8** | Brown | **CHASSIS_GND**| Spare / Thermistor Shield / GND | System Ground |

---

## 4. Step-by-Step Assembly Instructions

### Step 1: Prepare 3D Printed Parts
1. Inspect the mating surfaces of [`rotodamper_base.stl`](../cad/stl/rotodamper_base.stl) and [`rotodamper_cap.stl`](../cad/stl/rotodamper_cap.stl). Remove any stringing or brim artifacts.
2. Verify that the bottom sealing ring on [`rotodamper_disc.stl`](../cad/stl/rotodamper_disc.stl) is flat and smooth. Sand lightly with 400-grit wet sandpaper on a flat surface if needed.
3. Install 4x M3 brass heat-set inserts into the 4 top corner holes of `rotodamper_base.stl` using a soldering iron set to $220^\circ\text{C}$ (or tap M3 threads directly).

### Step 2: Install 5015 Blower Fan
1. Orient the 5015 blower fan with its rectangular exhaust nozzle ($20 \times 15\,\text{mm}$) facing the internal airway duct leading to the lower plenum.
2. Insert the blower fan into the base pocket from the bottom.
3. Route the fan wires (Red & Black) through the internal vertical wire pass-up channel up toward the rear cap mating line.
4. Place [`rotodamper_fan_cover.stl`](../cad/stl/rotodamper_fan_cover.stl) over the bottom of the base.
5. Fasten the cover using 4x M3 $\times 8\,\text{mm}$ countersunk screws.

### Step 3: Calibrate and Mount MG90S Servo
1. Connect the MG90S servo to your ESP32 controller.
2. Run the servo calibration script:
   - Command servo to **$0^\circ$** (Closed position).
   - Command servo to **$90^\circ$** (Fully Open position).
3. With the servo holding at **$90^\circ$ (Open)**:
   - Insert the white nylon double-arm servo horn into the recessed pocket on the top of [`rotodamper_disc.stl`](../cad/stl/rotodamper_disc.stl).
   - Align the disc's tactile indicator tab with the forward centerline (+Y), so the disc's $80^\circ$ aperture perfectly matches the base sector port.
   - Secure the horn into the disc hub with the central M2 servo horn screw.
4. Mount the MG90S servo body upside down into the rectangular pocket of [`rotodamper_cap.stl`](../cad/stl/rotodamper_cap.stl).
5. Secure the servo mounting flanges using 2x M2 $\times 8\,\text{mm}$ self-tapping screws.

### Step 4: Assemble Damper Disc & Test Throttling
1. Place [`rotodamper_disc.stl`](../cad/stl/rotodamper_disc.stl) into the circular recess of `rotodamper_base.stl`.
2. Apply a dry graphite powder lubricant or a micro-drop of food-grade silicone oil to the bottom sealing land.
3. Secure the disc using 1x M2.5 $\times 8\,\text{mm}$ pan head screw and nylon washer into the base pivot boss. Tighten just until snug, then back off $1/4$ turn so the disc spins freely with zero binding.
4. Verify rotation:
   - At $0^\circ$: Sector opening is 100% obstructed by the solid plate.
   - At $90^\circ$: Sector opening aligns 100% with the base port.

### Step 5: Wire the RJ45 Socket & Mate Cap to Base
1. Solder or crimp the fan leads and servo leads to the 8P8C RJ45 jack according to the pinout table above.
2. Snap or press the RJ45 jack into the rear pocket of [`rotodamper_cap.stl`](../cad/stl/rotodamper_cap.stl).
3. Lower `rotodamper_cap.stl` onto `rotodamper_base.stl`, guiding the MG90S servo output spline into the disc hub.
4. Fasten the cap to the base using 4x M3 $\times 25\,\text{mm}$ socket head cap screws into the corner counterbores.
5. Stretch 1x Dash-121 silicone O-ring into the nozzle groove.

---

## 5. Architectural Comparison: Design 1 vs Design 2

| Specification / Attribute | Design 1: Integrated Barrel Pod (`cad/smoker_damper.scad`) | Design 2: Roto-Damper Puck (`cad/roto_damper.scad`) |
| :--- | :--- | :--- |
| **Valve Mechanism** | Cylindrical Barrel Rotor ($27.1\,\text{mm}$ OD $\times 33.9\,\text{mm}$ L) with rectangular cross-bore | Flat Rotary Disc ($48.0\,\text{mm}$ OD $\times 2.5\,\text{mm}$ T) with $80^\circ$ sector aperture |
| **Airflow Throttling** | Linear throat opening ($0^\circ\text{--}90^\circ$) | Proportional radial area sweep ($0^\circ\text{--}90^\circ$) |
| **Chimney Draft Sealing** | Cylindrical barrel wall with knurled end-bezel | Planar face contact with raised $0.4\,\text{mm}$ low-friction sealing land + $10^\circ$ solid overlap barrier |
| **Servo Coupling** | Horizontal internal horn pocket inside rotor | Direct coaxial vertical spline engagement with disc hub |
| **Electronics Packaging** | All-in-one onboard bay (ESP32, USB-C, MOSFET, thermocouple) directly attached to damper | Tethered RJ45 umbilical to external controller / green perfboard |
| **Form Factor / Dimensions**| Horizontal pod ($148 \times 62 \times 52\,\text{mm}$) | Compact clamshell puck ($104 \times 56 \times 42\,\text{mm}$) |
| **Fan Compatibility** | Standard 5015, parametric scaling for 7530 / 9733 | Optimized for 5015 centrifugal blower |
| **Smoker Interface** | 31.5mm BBQ Guru nozzle (Dash-121 O-ring) | Identical 31.5mm BBQ Guru nozzle (Dash-121 O-ring) |
| **Best Used For** | Standalone all-in-one builds with direct USB-C power on the smoker | Remote controller setups, weather-protected base units, and classic HeaterMeter community hardware |

---

## 6. STL Compilation & Rendering Commands

To recompile or render any part from source:

```bash
# Export all 4 Roto-Damper STLs with clean 2-manifold geometry:
openscad -o cad/stl/rotodamper_base.stl -D 'part="base"' cad/roto_damper.scad
openscad -o cad/stl/rotodamper_disc.stl -D 'part="disc"' cad/roto_damper.scad
openscad -o cad/stl/rotodamper_cap.stl -D 'part="cap"' cad/roto_damper.scad
openscad -o cad/stl/rotodamper_fan_cover.stl -D 'part="fan_cover"' cad/roto_damper.scad

# Render the high-resolution exploded CAD technical diagram:
uv run --with numpy-stl --with matplotlib --with pillow python cad/render_rotodamper_assembly.py
```

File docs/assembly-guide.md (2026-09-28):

# 3D Printed Parts Assembly Guide

> Mechanical assembly instructions and exploded parts diagram for the ESP32 Smoker Controller and Airflow Damper System.

---

## 1. Exploded Assembly Diagram

The technical diagram below illustrates how each 3D-printed component and off-the-shelf electro-mechanical part fits together:

Exploded Assembly Diagram

---

## 2. Parts Index & Bill of Materials

### 2.1 3D Printed Components (Located in [`cad/stl/`](../cad/stl/))

| Exact STL Filename | Description | Quantity | Material Recommendation |
| :--- | :--- | :---: | :--- |
| [`smoker_housing.stl`](../cad/stl/smoker_housing.stl) | Central chassis body containing the 5015 blower pocket, lateral through-bore damper sleeve, horizontal MG90S servo bracket, and electronics bay. | 1 | PETG / ABS / ASA |
| [`damper_rotor.stl`](../cad/stl/damper_rotor.stl) | Cylindrical rotating barrel valve (27.1mm OD x 33.9mm L) with knurled left retaining bezel, 20x15mm airflow aperture, internal servo horn pocket, and 5.5mm axial screwdriver tunnel. | 1 | PETG / ABS / ASA |
| [`bbq_guru_vision_pro_nozzle_adapter.stl`](../cad/stl/bbq_guru_vision_pro_nozzle_adapter.stl) | 31.5mm OD cylindrical output nozzle featuring Dash-121/122 O-ring groove, 38mm stop collar, and 4-bolt mounting flange. | 1 | PETG / ABS / ASA |
| [`fan_cover.stl`](../cad/stl/fan_cover.stl) | Intake protection grille with concentric flow rings and crossbars to prevent finger/debris contact with blower impeller. | 1 | PETG / PLA / ABS |
| [`electronics_lid.stl`](../cad/stl/electronics_lid.stl) | Vented snap/screw lid protecting the ESP32, MAX31855, and MOSFET circuit with heat exhaust louvers. | 1 | PETG / PLA / ABS |
| [`vision_pro_kamado_slide_plate.stl`](../cad/stl/vision_pro_kamado_slide_plate.stl) | Direct-fit curved slide plate ($R = 195\,\text{mm}$) with 31.8mm (1-1/4") female receiver port for Vision Kamado Pro S-Series draft doors. | 1 | PETG / ABS / ASA |

### 2.2 Commercial Off-the-Shelf (COTS) Hardware & Fasteners

| Hardware Item | Purpose | Quantity |
| :--- | :--- | :---: |
| **5015 DC Radial Blower Fan (5V)** | Centrifugal combustion air induction fan ($50\text{mm} \times 15\text{mm}$) | 1 |
| **TowerPro MG90S Micro-Servo** | Metal-gear servo motor driving the rotating damper rotor | 1 |
| **Dash-121 or Dash-122 Silicone O-Ring** | High-temp friction seal on nozzle adapter ($28.3\text{mm} \text{ ID} \times 2.6\text{mm} \text{ CS}$) | 1 |
| **M3 x 20mm Socket Head Screws** | Secures `fan_cover.stl` and 5015 blower fan to housing body | 3 |
| **M3 x 10mm Socket Head Screws** | Secures `bbq_guru_vision_pro_nozzle_adapter.stl` to front housing boss | 4 |
| **M2 x 8mm Self-Tapping Screws** | Secures MG90S servo mounting ears to bracket tower | 2 |
| **M3 x 6mm Button Head Screws** | Secures `electronics_lid.stl` to electronics bay corner posts | 2 |
| **Servo Arm / Horn Screw** | Secures horn to servo brass output spline (included with MG90S) | 1 |

---

## 3. Step-by-Step Assembly Procedure

### Step 1: Damper Rotor & Servo Subassembly
1. Power the ESP32 or servo tester on the bench to zero the MG90S servo position ($0^\circ = \text{closed}$ damper aperture).
2. Insert the MG90S servo horizontally into the servo bracket cavity on the right side of [`smoker_housing.stl`](../cad/stl/smoker_housing.stl) with its output spline passing through the 12.5mm dividing wall opening into the damper barrel. Secure the servo ears with two M2x8mm screws.
3. Take the single-arm servo horn provided with the MG90S and press-fit it into the drive-end pocket of [`damper_rotor.stl`](../cad/stl/damper_rotor.stl).
4. Slide [`damper_rotor.stl`](../cad/stl/damper_rotor.stl) directly into the open cylindrical bore from the **left face** of [`smoker_housing.stl`](../cad/stl/smoker_housing.stl) until the rotor horn engages the servo spline and the knurled retaining bezel rests flush against the sleeve face.
5. Insert a magnetic M2 screwdriver through the 5.5mm central axial tunnel in the rotor's left knurled flange and tighten the servo center screw directly into the brass spline.
6. Verify smooth $90^\circ$ rotation:
   * **$0^\circ$ (Closed)**: Damper barrel solid wall blocks the airway completely (anti-chimney draft). Pointer indicates Closed.
   * **$90^\circ$ (Open)**: Rectangular cross-bore aligns 100% with the 20x15mm airway channel.

### Step 2: Blower Fan & Intake Grille Installation
1. Route the 5015 blower fan red (+) and black (-) wires through the wiring pass-through slot into the electronics bay.
2. Drop the 5015 blower fan into the square pocket on [`smoker_housing.stl`](../cad/stl/smoker_housing.stl) with the rectangular exhaust throat pointing toward the damper transition duct.
3. Place [`fan_cover.stl`](../cad/stl/fan_cover.stl) over the fan intake.
4. Fasten the cover and fan to the housing using three M3x20mm screws into the pilot holes. Do not overtighten.

### Step 3: Nozzle Adapter & O-Ring Fitment
1. Stretch the high-temperature silicone O-Ring (Dash-121 or Dash-122) over the tip of [`bbq_guru_vision_pro_nozzle_adapter.stl`](../cad/stl/bbq_guru_vision_pro_nozzle_adapter.stl) and seat it in the retention groove ($10\,\text{mm}$ back from the nozzle tip).
2. Align the nozzle adapter's 4 mounting holes with the threaded boss on the front of [`smoker_housing.stl`](../cad/stl/smoker_housing.stl).
3. Secure the adapter plate using four M3x10mm screws.

### Step 4: Electronics Installation & Lid Closure
1. Place the ESP32 DevKit, MAX31855 thermocouple amplifiers, and MOSFET module inside the rear bay of [`smoker_housing.stl`](../cad/stl/smoker_housing.stl) according to [docs/wiring-diagram.md](wiring-diagram.md).
2. Connect the servo signal lead (Orange) to `GPIO 26` and blower fan gate lead to `GPIO 25`.
3. Route the USB-C / micro-USB power cable through the side wall notch.
4. Align [`electronics_lid.stl`](../cad/stl/electronics_lid.stl) over the bay and press until the inner centering lip seats inside the perimeter. Secure with two M3x6mm screws.

### Step 5: Kamado Grill Mounting
1. Remove the factory bottom draft door slide on your Vision Pro Kamado grill.
2. Slide [`vision_pro_kamado_slide_plate.stl`](../cad/stl/vision_pro_kamado_slide_plate.stl) directly into the curved bottom track until fully seated.
3. Insert the assembled controller pod's 31.5mm nozzle into the 31.8mm female receiver port on the slide plate.
4. Push firmly until the 38mm stop collar rests flush against the receiver tube face. The silicone O-ring provides an airtight, vibration-damped friction fit.

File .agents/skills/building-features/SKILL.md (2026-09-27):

---
name: building-features
description: Builds and extends features using the onion/ports-and-adapters architecture — inside-out construction, a required pre-implementation plan, and a completion audit. Use when implementing a new feature or changing application structure.
---

# Building Features

Use this skill when implementing a new feature or changing application structure. Work
proceeds from the inside outward — Domain first, transport and vendors last — with a
required plan before implementation and a completion audit before completing the change.

Read [docs/architecture.md](../../../docs/architecture.md) and follow it directly. It is
the single source of truth for:

- The mandatory dependency rules for Domain, Services, Services.Ports, Repositories,
  Adapters, Controller, and Utilities
- The Feature Construction Procedure
- The Complexity Controls (prohibited patterns)
- The Required Agent Plan, produced before implementation
- The Required Completion Audit, verified before completing the change

Apply its MUST / SHOULD / MAY requirements exactly as written.

When the feature includes a browser client, also use the
[building-ui](../building-ui/SKILL.md) skill.
[docs/architecture.md](../../../docs/architecture.md) governs the boundary between the
client and the backend; [docs/ui-architecture.md](../../../docs/ui-architecture.md)
governs everything inside the client.

When the work changes trust boundaries, authentication, authorization, secrets, or
isolation, also follow [docs/security.md](../../../docs/security.md). Build security in
from the start rather than relying on review to find its absence.

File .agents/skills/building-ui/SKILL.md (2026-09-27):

---
name: building-ui
description: Builds browser-based user interfaces against the constrained UI stack — Next.js App Router, Tailwind, shadcn/ui — with rules for placement, data access, accessibility, API integration, and UI verification. Use when implementing or changing a web client.
---

# Building UI

Use this skill when implementing or changing a browser-based web client. A web client is a
`Clients` entry in the Architecture Canon: this skill governs its internals, while
[docs/architecture.md](../../../docs/architecture.md) governs its relationship to the
backend.

Read [docs/ui-architecture.md](../../../docs/ui-architecture.md) and follow it directly. It
is the single source of truth for:

- Client placement under `Clients` and the boundary with backend code
- The mandated stack: Next.js App Router, Tailwind, shadcn/ui, Lucide, next-themes
- Data access — Server Components own reads, mutations go through `services/`, and the
  narrow conditions under which a client-side server-state library is permitted
- The design system: semantic colors, type scale, spacing grid
- Accessibility requirements and the automated check in the end-to-end suite
- Directory layout, API integration, error handling, loading states, forms, and auth
- UI-specific verification, including Playwright coverage against the real backend
- The Required Agent Plan, produced before implementation
- The Required Completion Audit, verified before completing the change

Apply its MUST / SHOULD / MAY requirements exactly as written.

The client is part of the system under verification. Internal dependencies — your client to
your backend — are never mocked. See
[docs/verification.md](../../../docs/verification.md) for the full verification contract.

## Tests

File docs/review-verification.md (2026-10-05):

# Review remediation verification

Feature: reliable wired K-type control and protected calibration.
Plan: [review remediation](plans/review-remediation.md).

Entry points: production firmware `setup()` and control/network tasks; the real
firmware HTTPS dispatch handler; the Python simulator CLI and its HTTPS dashboard.
Environment: Linux host, C++17, pinned PlatformIO ESP32 framework, Chromium.
External boundaries: SPI/PWM/GPIO/NVS and RTOS spies; real JSON/crypto libraries;
real local TLS sockets, filesystem, simulator process, browser, and accessibility engine.
Driver: `tools/verify.sh --firmware --browser`.

## Acceptance matrix

| Scenario and input | Expected state/output and failure behavior | Evidence | Result |
| --- | --- | --- | --- |
| Boot with persisted inverted calibration | Fan off before initialization; saved limits applied to first closure pulse; construction performs no platform I/O | `test_startup.cpp`, `test_hardware.cpp` | PASS |
| Demand from zero through forced airflow | Closed/off at zero; fan stays off below threshold; preserve configured minimum fan duty | `test_domain.cpp`, `test_control.cpp`, Python control tests | PASS |
| One MAX31855K pit probe, no food converter | Valid pit controls normally; missing optional food does not inhibit control | `test_control.cpp`, `test_hardware.cpp`, startup harness | PASS |
| Signed/boundary temperatures and converter faults | Correct decode; invalid pit clamps previously active fan and damper, including between PID cycles | `test_control.cpp`, hardware tests and Python tests | PASS |
| Lid pause/fault followed by recovery | No integration over inhibited time; resume with retained integral and valid timing | `test_control.cpp`, `test_control_contracts.py` | PASS |
| Copied probe name after source stack reuse | Telemetry and display retain owned strings | `test_control.cpp`; sanitizers | PASS |
| Concurrent sensor/display and wireless traffic | Complete SPI frame ownership and copied wireless state | `test_hardware.cpp`, `test_wireless_concurrency.cpp` | PASS |
| Bounded/stale control commands | Control owner applies queued command; full queue rejects; stale version preserves current settings | Control and HTTP tests | PASS |
| Missing/wrong auth, untrusted Host/Origin, private file path, malformed/oversize JSON | Requests rejected without settings mutation or token disclosure | `test_web_api.py`, production `test_web_security.cpp` | PASS |
| Valid calibration, invalid limits, token preservation/removal | Applied/saved feedback; invalid settings leave storage intact; token never echoed | Real HTTPS tests and `tools/test_browser.py` | PASS |
| Restart or filesystem/NVS save failure | Fresh instance loads settings; stale forms remain rejected after reboot; failed persistence distinguished from applied setting | Storage tests, HTTPS tests and browser process restart | PASS |
| Keyboard/mobile/light and dark themes | Reachable controls, no 360px horizontal overflow, no tested WCAG A/AA axe violations | Real Chromium/axe browser driver | PASS |
| Slow or blocked TLS handshake/read/write; failed connection setup | Fixed connection slots and absolute deadlines; TLS context and socket released exactly once | `test_https_transport.cpp`, real Python HTTPS deadline tests | PASS |
| Repeated BLE advertisements; change an incorrect probe MAC | Bounded candidate retention and fresh service discovery after reconnect | `test_ble_discovery.cpp` | PASS |
| 200 BLE discoveries with 64 instances of each of three service UUIDs | Exactly three owned services retained; both indexes cleared between rounds; zero live services after destruction | `test_ble_sdk_patch.py`, emitted Arduino source bodies | PASS |

## Original finding coverage

| Finding | Implemented correction |
| --- | --- |
| Fan/servo shared LEDC timer | Fan channel 0, servo channel 2; timer isolation and pulse assertions |
| Missing boot closure pulse | Explicit initialized state and calibrated first drive |
| Unserialized SPI and absent display MOSI | Injected shared bus; CS/transaction lifetime under one lock; MOSI23 enabled |
| Cross-task service mutation | Bounded typed command queue and copied state; exclusive control owner |
| NVS access in global construction | Side-effect-free construction and explicit initialization after platform startup |
| PID windup across suppression | Suspend integration/time history through fault and lid intervals |
| Dangling telemetry probe name | Domain-owned fixed-size string storage and copied snapshots |
| Shared credentials, unauthenticated commands, exposed tokens | Per-device provisioned HTTPS; authenticated routes; write-only token; offline CA key |
| Missing persisted servo calibration | Validated domain limits, actuator port, complete storage record and dashboard controls |
| Domain importing a Services port | Domain owns telemetry; port retains compatibility alias |
| MAX31856 advertised without driver | Selectable K-type driver, nonblocking conversion, fault/readiness/freshness checks |
| Weak fault tests and strict-build failure | Active-output regression/mutations, decoder boundaries, actual Arduino paths and warning-free host checks |

Review follow-ups additionally preserve minimum blower speed on configuration updates,
refresh the servo timeout clock after acquisition, reject bad converter register readback,
bound slow HTTPS requests, keep malformed provisioning from stopping simulator
control, and reserve configuration revisions durably across reboots and failed saves.
Additional transport/browser assertions cover successful setpoint, pause/resume,
changing telemetry, binary TLS forwarding, and partial/failed response writes.
BLE discovery uses one explicit scanner owner and bounded advertisement retention;
reconnects refresh the SDK's cached services. Failed HTTPS setup leaves socket closure
to the SDK accept caller, while established sessions close their own socket.
An SDK-source-checked build patch repairs Arduino's duplicate-service allocation leak
and stale secondary index without modifying the installed framework. Reused HTTPS
slots also exercise allocation/handshake failure followed by a healthy connection.

## Physical gates

Software evidence covers the control and transport behavior of the remediation.
It does not qualify the full physical [project North Star](north-star.md).
No serial ESP32 device was attached during this work.

- Gate 1: timer allocation and pulses verified at the driver boundary; actual 25 kHz
  fan PWM, 50 Hz servo signal, RJ45 wiring, jitter, power integrity and movement need
  bench measurements.
- Gate 2: demand mapping and command ordering verified in software; actual aperture
  and blower response remain unmeasured.
- Gate 3: suppression and recovery verified in software; ±2°F smoker regulation is
  untested.
- Gate 4: every decoded pit fault clamps active outputs in the same control cycle.
  The boundary model verifies eight MAX31856 disconnect phases with clamp
  79–181 ms after disconnect; MAX31855 fault checking also runs between PID cycles.
  Actual unplug-to-shutdown latency, including electrical conversion behavior and
  task scheduling, still needs a device timing test.
- Gate 5: real simulator HTTPS/browser and fresh-instance storage are tested; actual
  ESP32 Wi-Fi/TLS behavior and power-cycle persistence need bench confirmation.

The optional MEATER cloud adapter now requires a supplied trusted CA and station
connectivity. The shipped composition leaves it disabled; a stored token alone does
not establish connectivity. Wired control remains independent of cloud access.

## Completion audit

Domain: owns calibration invariants, PID suppression and value-owned telemetry/control
messages; imports no Ports or hardware dependencies.

Services: explicit startup and one control owner; calibration, fault shutdown,
configuration application and command consumption depend only on Ports.

Ports: narrow sensor, actuator, storage, telemetry and bounded command/state contracts;
no vendor types cross inward.

Repositories: no new repository abstraction; existing configuration storage remains
sufficient.

Adapters: own PWM/SPI/NVS/RTOS/crypto/network behavior and external failure translation.

Controller: constructs ownership after Arduino startup, wires dependencies and schedules
tasks. Network tasks consume copied state and do not mutate service state.

Tests: production control regressions, hardware/startup spies, mutation checks, real
TLS API and browser drivers, strict compiles, and both ESP32 converter builds.

Architecture notes: Domain → Services/Ports stays shallow with inward dependencies;
no global mutable service dependencies or service locator. The user approved retaining
the embedded dashboard as the documented exception to the Next.js client requirement.

## Review and execution results

Software verification on October 4, 2026, at code commit `0165497`:

- `tools/verify.sh --firmware --browser`: exit 0; 120 Python tests, all 13 C++
  domain suites, control regressions, strict native entrypoint, hardware/startup and
  wireless tests, production HTTPS handler/transport tests, both ESP32 builds, and
  the complete real simulator/browser flow passed.
- AddressSanitizer and UndefinedBehaviorSanitizer: domain/control suites passed.
- Targeted mutation checks rejected regressions in calibrated first pulse, baseline
  scalar NVS migration, fault shutdown/timing, MAX31856 bus mode/readback, setpoint,
  pause/resume, telemetry updates, TLS send/read forwarding, reused socket ownership,
  BLE peer-service refresh, duplicate allocation, and secondary-index cleanup.
- The default build uses 64,208 bytes of RAM and 1,835,841 bytes of flash;
  MAX31856 uses 64,320 bytes and 1,836,761 bytes. Both fit the existing partition
  (19.6% RAM, 70.0–70.1% application flash). No device was flashed.

Independent Correctness, Architecture, Test, and Security reviewers reported no
remaining findings through `0165497`, each with high confidence. Findings were
repaired and re-reviewed, including the final socket-reuse and vendor BLE ownership
regressions. Coordinator's consolidated code-review result: **PASS**.

North Star criteria: all software scenarios above PASS. Physical Gates 1–5 remain
NOT TESTED as qualified in the physical-gates section. The remaining work is bench
qualification; no code-review findings are intentionally deferred.

Final verification result: **PARTIALLY VERIFIED** against the full project North Star,
with all remediation software scenarios passing and physical qualification pending.

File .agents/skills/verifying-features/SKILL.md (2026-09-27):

---
name: verifying-features
description: Verifies a completed feature end-to-end against its North Star through executable system behavior, driving a real entry point and collecting evidence. Use when a feature is code-complete and needs acceptance verification.
---

# Verifying Features

Use this skill when a feature is code-complete and needs acceptance verification. A
feature is not complete because its code compiles or its unit tests pass — it is
complete when the system can be exercised through an external entry point and its
behavior matches the North Star.

Read [docs/verification.md](../../../docs/verification.md) and follow it directly. It is
the single source of truth for:

- Verification inputs and the required pre-verification plan
- The eight-step procedure, from defining the verification model through adjust-and-repeat
- Verification scope and the required Verification Report

Build the verification driver to fit the feature's actual entry point — scripted HTTP
requests, a CLI harness, a Playwright test, an event producer, a job runner. Every
driver is feature-specific; the driver contract in the source document is the template.

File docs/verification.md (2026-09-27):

# Agent Verification Contract

This contract governs **feature and epic verification** — the final validation that an
integrated system satisfies the North Star. For step-level validation, use code review
and unit tests (see `reviewing-code` skill).

## Objective

Verify completed end-to-end features against the North Star through executable system behavior.

Verification must prove that the integrated feature:

- Behaves as intended
- Preserves invariants
- Handles expected failure paths
- Works through a real controller or client boundary
- Produces observable evidence of correctness

A feature is not complete because its code compiles or its unit tests pass.

It is complete when the system can be exercised through an external entry point and its behavior matches the North Star.

---

# Verification Inputs

Before verification begins, review:

- The North Star
- Epic context
- Step requirements
- Acceptance criteria
- Architecture Canon ([architecture.md](architecture.md))
- Existing tests and system interfaces

Extract the behavior that must be demonstrated.

Do not infer success from implementation structure alone.

---

# 1. Define the Verification Model

Identify:

- Feature entry points
- External systems
- Required inputs
- Expected outputs
- State transitions
- Invariants
- Failure paths
- Observable side effects

Produce a verification matrix:

```text
Scenario:
Input:
External conditions:
Expected output:
Expected state change:
Invariant exercised:
Failure behavior:
```

Every North Star acceptance criterion and critical invariant MUST map to at least one executable scenario.

Critical invariants SHOULD be exercised through both valid and invalid paths.

---

# 2. Prepare External Boundaries

Identify all external dependencies involved in the feature.

Examples:

- Databases
- Third-party APIs
- Message brokers
- Filesystems
- Email providers
- Payment gateways
- Time
- Randomness
- Authentication providers
- External services

For each dependency, determine whether verification should use:

- A mock
- A fake
- A local emulator
- A disposable real instance
- A controlled test environment

Use the lightest boundary implementation that still proves the required behavior.

## Mocks

Use mocks when verifying:

- Exact interaction behavior
- Failure responses
- Timeouts
- Retries
- Rare external conditions
- Deterministic branching

## Fakes

Use fakes when verifying:

- Stateful workflows
- Repository behavior
- Repeated interactions
- Realistic feature paths
- Multiple scenarios without external infrastructure

## Real integrations

Use targeted real integrations when behavior depends on:

- Database semantics
- Serialization compatibility
- Network protocols
- SDK behavior
- Transactions
- External system contracts

Do not mock the behavior being verified.

External test implementations MUST preserve the behavioral contract of their Ports.

---

# 3. Build Test Data

Create deterministic data that exercises the full feature.

Test data SHOULD include:

- Standard valid input
- Boundary values
- Invalid input
- Missing data
- Conflicting state
- Duplicate requests
- External failures
- Retry conditions
- Permission failures
- Invariant violations

Test data MUST be:

- Repeatable
- Isolated
- Easy to understand
- Easy to reset
- Explicitly connected to a verification scenario

Avoid random data unless the random seed is fixed and recorded.

---

# 4. Select the System Entry Point

Exercise the feature through the highest practical external boundary.

Examples:

```text
HTTP API
CLI
Web SPA
Mobile client
Scheduled job
Event consumer
Worker
```

Prefer verifying through the interface an actual consumer uses.

Examples:

```text
HTTP API -> scripted HTTP requests
CLI      -> command execution
SPA      -> Playwright
Worker   -> controlled event publication
Job      -> explicit job invocation
```

Do not bypass the Controller by invoking Services directly for end-to-end verification.

Service-level tests support verification but do not replace it.

When the entry point is a browser client, [ui-architecture.md](ui-architecture.md) states the additional
UI-specific requirements: internal client-to-backend dependencies are never mocked, the
application must start from a single command, and Playwright must cover every North Star
capability against the real backend.

---

# 5. Build the Verification Driver

Create an executable driver that operates the selected entry point.

Examples:

- Shell script using `curl`
- API test script
- CLI harness
- Playwright test
- Event producer
- Worker runner
- Scenario test executable

The driver MUST:

- Prepare required state
- Supply deterministic inputs
- Exercise each scenario
- Capture outputs
- Capture relevant side effects
- Report failures clearly
- Return a failing exit status when expectations are not met
- Be repeatable without manual intervention
- Be proven to fail when the system does

The driver SHOULD live with the repository and remain reusable.

Manual verification alone is insufficient for repeatable feature acceptance.

---

# 6. Execute and Collect Evidence

Run the complete system with the selected mocks, fakes, emulators, or controlled integrations.

For each scenario, collect:

- Input
- Output
- Exit status or response status
- Relevant persisted state
- Emitted events
- External interactions
- Logs required to explain behavior
- Screenshots when verifying visual clients

Evidence MUST be sufficient to determine whether the North Star behavior occurred.

Logs alone are not proof unless the expected behavior is itself log output.

Prefer assertions against externally observable behavior and durable state over internal calls, logs, or implementation details.

---

# 7. Evaluate Against the North Star

Compare observed behavior directly against:

- Expected behavior
- Acceptance criteria
- Invariants
- Constraints
- Failure semantics
- Non-goals

Classify each scenario:

```text
PASS
FAIL
BLOCKED
NOT TESTED
```

A scenario MUST NOT be marked complete without executable evidence.

When behavior differs from the North Star, determine whether:

- The implementation is incorrect
- The test environment is incorrect
- The driver is incorrect
- The North Star is ambiguous or outdated

Do not silently redefine expected behavior to match the implementation.

---

# 8. Adjust and Repeat

For every failure:

1. Identify the root cause.
2. Correct the implementation, test environment, data, or driver.
3. Rerun the failed scenario.
4. Rerun affected neighboring scenarios.
5. Rerun the full verification suite when changes may have broader impact.

Repeat until all required scenarios pass.

A fix is incomplete if it only changes the observed symptom without preserving the North Star invariants.

---

# Verification Scope

End-to-end verification MUST cover:

- Primary success path
- Important alternate paths
- Critical validation failures
- External dependency failures
- State transitions
- Declared invariants
- Observable side effects
- Relevant authorization boundaries
- Idempotency or retry behavior when required

Verification SHOULD prioritize business risk over exhaustive input combinations.

Unit and integration tests provide depth.

End-to-end verification provides confidence that the complete system works through its real boundaries.

---

# Required Agent Plan

Before building the verification system, produce:

```text
North Star behaviors:
Entry point:
External dependencies:
Mocks:
Fakes:
Real integrations:
Test data:
Scenarios:
Driver:
Evidence:
```

Use `None` where appropriate.

---

# Required Verification Report

Complete verification with:

```text
Feature:
Entry point:
Environment:
External boundaries:
Driver:

Scenarios:
- Scenario:
  Result:
  Evidence:

North Star criteria:
- Criterion:
  Result:

Adjustments made:
Remaining gaps:
Final result:
```

The final result MUST be one of:

```text
VERIFIED
NOT VERIFIED
PARTIALLY VERIFIED
BLOCKED
```

`VERIFIED` requires all mandatory North Star criteria and critical invariants to pass.

---

# Governing Principle

Verification must operate the system, not merely inspect it.

Use controlled external boundaries, deterministic data, and executable drivers to prove that observable behavior matches the North Star.

Build.

Exercise.

Observe.

Compare.

Correct.

Repeat.

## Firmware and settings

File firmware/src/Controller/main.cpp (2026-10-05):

/** ESP32 composition root: construct ownership after Arduino startup. */
#ifdef ARDUINO
#include <Arduino.h>
#else
#include <iostream>
#endif
#include "../Adapters/Actuators/ESP32PWMBlowerAdapter.hpp"
#include "../Adapters/Actuators/ESP32ServoDamperAdapter.hpp"
#include "../Adapters/Hardware/SharedSpiBus.hpp"
#include "../Adapters/Runtime/BoundedControlChannel.hpp"
#include "../Adapters/Sensors/MAX31855SensorAdapter.hpp"
#include "../Adapters/Sensors/MAX31856SensorAdapter.hpp"
#include "../Adapters/Sensors/BLEProbeAdapter.hpp"
#include "../Adapters/Sensors/MeaterBleClientAdapter.hpp"
#include "../Adapters/Sensors/MeaterCloudAdapter.hpp"
#include "../Adapters/Sensors/CompositeSensorAdapter.hpp"
#include "../Adapters/Telemetry/SerialTelemetryAdapter.hpp"
#include "../Adapters/Network/WebServerAdapter.hpp"
#include "../Adapters/Storage/ESP32NVSConfigAdapter.hpp"
#include "../Adapters/Display/InlandEInkAdapter.hpp"
#include "../Services/SmokerControlService.hpp"

#ifndef SMOKER_FOOD_CS
#define SMOKER_FOOD_CS -1
#endif

using namespace SmokerController;

class Application {
public:
    bool initializeHardware() {
        blower.begin(); // Fan off before storage, display, or network work.
        control.initialize(); // Load persisted calibration before the first servo pulse.
        damper.begin();
        if (!spi.begin(18, 19, 23)) return false;
        // Deassert every chip before the first transaction on the shared bus.
#ifdef ARDUINO
        pinMode(4, OUTPUT);
        digitalWrite(4, HIGH);
#endif
        wired.begin();
        sensors.setMode(control.config().meat_probe_mode);
        return true;
    }
    void controlStep(uint32_t now) {
        sensors.setMode(control.config().meat_probe_mode);
        control.executeCycle(now);
    }
    void maintainSensor() {
#ifdef SMOKER_MAX31856
        wired.update();
#endif
    }
    void maintainActuator(uint32_t now) { damper.update(now); }
    void verifySafety(uint32_t now) { control.verifyPitSafety(now); }
    void initializeNetwork() {
        display.begin();
#ifdef ARDUINO
        scanner.begin(passiveBle, directBle);
#endif
        directBle.begin();
        web.begin();
    }
    void networkStep(uint32_t now) {
        Domain::ControlState state;
        if (channel.snapshot(state)) {
            passiveBle.setTargetMac(state.config.meater_mac_filter);
            directBle.setTargetMac(state.config.meater_mac_filter);
            directBle.setEnabled(state.config.meat_probe_mode == Domain::MeatProbeMode::MeaterBleDirect);
            cloud.setApiToken(state.config.meater_cloud_token);
            cloud.setEnabled(state.config.meat_probe_mode == Domain::MeatProbeMode::MeaterCloud);
            display.update(now, Domain::DisplayView::fromTelemetry(state.telemetry));
        }
        web.update();
        passiveBle.update(now);
        directBle.update(now);
        cloud.update(now);
    }
private:
    Adapters::Hardware::SharedSpiBus spi;
    Adapters::Actuators::ESP32PWMBlowerAdapter blower{25, 0};
    Adapters::Actuators::ESP32ServoDamperAdapter damper{26, 2};
#ifdef SMOKER_MAX31856
    Adapters::Sensors::MAX31856SensorAdapter wired{spi, 5, SMOKER_FOOD_CS};
#else
    Adapters::Sensors::MAX31855SensorAdapter wired{spi, 5, SMOKER_FOOD_CS};
#endif
    Adapters::Display::InlandEInkAdapter display{spi, 4, 22, 16, 17};
    Adapters::Sensors::SharedBleScanner scanner;
    Adapters::Sensors::BLEProbeAdapter passiveBle;
    Adapters::Sensors::MeaterBleClientAdapter directBle{30000, &scanner};
    Adapters::Sensors::MeaterCloudAdapter cloud;
    Adapters::Sensors::CompositeSensorAdapter sensors{wired, &passiveBle, &directBle, &cloud};
    Adapters::Telemetry::SerialTelemetryAdapter telemetry;
    Adapters::Storage::ESP32NVSConfigAdapter storage;
    Adapters::Runtime::BoundedControlChannel channel;
    Services::SmokerControlService control{ sensors, damper, blower, &telemetry, 225.0f,
        Domain::ActuatorCoordinator{}, Domain::PIDConfig{}, &storage, &channel };
    Adapters::Network::WebServerAdapter web{channel};
};

#ifdef ARDUINO
void controlLoopTask(void* context) {
    auto& app = *static_cast<Application*>(context);
    TickType_t lastWake = xTaskGetTickCount();
    uint32_t lastSample = millis() - 1000U;
    for (;;) {
        app.maintainSensor();
        const uint32_t now = millis();
        if (now - lastSample >= 1000U) {
            app.controlStep(now);
            lastSample = now;
        }
        // Acquisition and persistence can advance the clock after a new servo
        // target records its movement time. Never pass that target an older time.
        app.verifySafety(millis());
        app.maintainActuator(millis());
        vTaskDelayUntil(&lastWake, pdMS_TO_TICKS(20));
    }
}
void networkLoopTask(void* context) {
    auto& app = *static_cast<Application*>(context);
    app.initializeNetwork();
    for (;;) {
        app.networkStep(millis());
        vTaskDelay(pdMS_TO_TICKS(10));
    }
}
void setup() {
    static Application app; // This owner is first constructed after platform startup.
    Serial.begin(115200);
    if (!app.initializeHardware()) {
        Serial.println("[Init] Shared bus unavailable; control remains off.");
        return;
    }
    if (xTaskCreatePinnedToCore(controlLoopTask, "SmokerControl", 6144, &app, 2, nullptr, 1) != pdPASS) {
        Serial.println("[Init] Control task unavailable; control remains off.");
        return;
    }
    if (xTaskCreatePinnedToCore(networkLoopTask, "SmokerNetwork", 8192, &app, 1, nullptr, 0) != pdPASS)
        Serial.println("[Init] Network task unavailable; autonomous control continues.");
}
void loop() { delay(1000); }
#else
int main() {
    Application app;
    if (!app.initializeHardware()) return 1;
    app.controlStep(1000);
    app.initializeNetwork();
    app.networkStep(1000);
    std::cout << "Native Host initialization verified cleanly.\n";
    return 0;
}
#endif

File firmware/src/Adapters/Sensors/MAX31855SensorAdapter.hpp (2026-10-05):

#pragma once

#include "../../Services/Ports/TemperatureSensorPort.hpp"
#include <cstdint>
#include "../Hardware/SharedSpiBus.hpp"

#ifdef ARDUINO
#include <Arduino.h>
#include <SPI.h>
#endif

namespace SmokerController::Adapters::Sensors {

class MAX31855SensorAdapter : public Services::Ports::ITemperatureSensorPort {
public:
    explicit MAX31855SensorAdapter(Hardware::SharedSpiBus& bus,
                                   uint8_t cs_pit_pin = 5, int8_t cs_food1_pin = -1) noexcept
        : bus_(bus), cs_pit_(cs_pit_pin), cs_food1_(cs_food1_pin) {}

    void begin() noexcept {
#ifdef ARDUINO
        pinMode(cs_pit_, OUTPUT);
        digitalWrite(cs_pit_, HIGH);
        if (cs_food1_ >= 0) {
            pinMode(cs_food1_, OUTPUT);
            digitalWrite(cs_food1_, HIGH);
        }
        started_ms_ = millis();
#endif
        begun_ = true;
    }

    Domain::TemperatureReading readTemperature(Domain::SensorRole role) noexcept override {
        uint32_t now_ms = 0;
#ifdef ARDUINO
        now_ms = millis();
#endif
        if (role != Domain::SensorRole::Pit && (role != Domain::SensorRole::Food1 || cs_food1_ < 0))
            return Domain::TemperatureReading{0.0f, role, now_ms, Domain::SensorFault::Disconnected};
        // MAX31855 datasheet rev. 5 p.4 specifies tCONV_PU = 200 ms.
        // https://www.analog.com/media/en/technical-documentation/data-sheets/MAX31855.pdf
        if (!begun_ || now_ms - started_ms_ < 200)
            return Domain::TemperatureReading{0.0f, role, now_ms, Domain::SensorFault::Stale};
        const uint8_t cs = role == Domain::SensorRole::Pit ? cs_pit_ : static_cast<uint8_t>(cs_food1_);
        return decodeRawReading(readRaw32(cs), role, now_ms);
    }

    static Domain::TemperatureReading decodeRawReading(
        uint32_t raw,
        Domain::SensorRole role,
        uint32_t timestamp_ms
    ) noexcept {
        // Bit 16 is the master fault bit
        if (raw & 0x00010000ULL) {
            // Probe fault detected
            Domain::SensorFault fault = Domain::SensorFault::OutOfRange;
            if (raw & 0x01) {
                fault = Domain::SensorFault::Disconnected; // Open circuit
            } else if (raw & 0x02) {
                fault = Domain::SensorFault::ShortToGnd;    // Short to GND
            } else if (raw & 0x04) {
                fault = Domain::SensorFault::ShortToVcc;    // Short to VCC
            }
            return Domain::TemperatureReading{0.0f, role, timestamp_ms, fault};
        }

        // Bits 31..18: 14-bit signed thermocouple temperature (0.25°C resolution)
        int32_t tc_raw = (raw >> 18) & 0x3FFF;
        // Sign extend if negative (bit 13 set)
        if (tc_raw & 0x2000) {
            tc_raw |= 0xFFFFC000;
        }

        float celsius = static_cast<float>(tc_raw) * 0.25f;
        return Domain::TemperatureReading{celsius, role, timestamp_ms, Domain::SensorFault::Ok};
    }

private:
    uint32_t readRaw32(uint8_t cs_pin) noexcept {
#ifdef ARDUINO
        Hardware::SharedSpiBus::Frame frame(bus_, cs_pin, 4000000, SPI_MODE0);
        if (!frame) return 0x00010001; // unavailable bus fails closed
        delayMicroseconds(1);
        uint32_t raw = 0;
        for (uint8_t i = 0; i < 4; ++i) raw = (raw << 8) | frame.transfer(0);
        return raw;
#else
        (void)cs_pin;
        return 0;
#endif
    }

    Hardware::SharedSpiBus& bus_;
    uint8_t cs_pit_;
    int8_t cs_food1_;
    uint32_t started_ms_{0};
    bool begun_{false};
};

} // namespace SmokerController::Adapters::Sensors

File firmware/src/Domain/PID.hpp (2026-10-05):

#pragma once

#include <algorithm>
#include <cstdint>
#include "Airflow.hpp"

namespace SmokerController::Domain {

struct PIDConfig {
    float kp{3.0f};
    float ki{0.02f};
    float kd{15.0f};
    float integral_min{0.0f};
    float integral_max{100.0f};
    float output_min{0.0f};
    float output_max{100.0f};
    float derivative_alpha{0.8f}; // Low-pass filter coefficient for derivative term
};

class PIDRegulator {
public:
    explicit PIDRegulator(float target_setpoint, const PIDConfig& config = {}) noexcept
        : setpoint_(target_setpoint),
          config_(config),
          integral_(0.0f),
          last_error_(0.0f),
          last_time_ms_(0),
          filtered_derivative_(0.0f),
          initialized_(false) {}

    [[nodiscard]] float setpoint() const noexcept { return setpoint_; }
    void setSetpoint(float value) noexcept { setpoint_ = value; }

    [[nodiscard]] const PIDConfig& config() const noexcept { return config_; }
    void setConfig(const PIDConfig& cfg) noexcept { config_ = cfg; }

    [[nodiscard]] float integral() const noexcept { return integral_; }

    void reset() noexcept {
        integral_ = 0.0f;
        last_error_ = 0.0f;
        last_time_ms_ = 0;
        filtered_derivative_ = 0.0f;
        initialized_ = false;
    }

    // Preserve accumulated steady-state bias, but exclude inhibited time and error
    // changes from the next integration and derivative update.
    void suspend() noexcept {
        initialized_ = false;
        filtered_derivative_ = 0.0f;
    }

    AirflowDemand compute(float current_temp, uint32_t current_time_ms) noexcept {
        const float error = setpoint_ - current_temp;

        if (!initialized_) {
            initialized_ = true;
            last_time_ms_ = current_time_ms;
            last_error_ = error;
            float p_term = config_.kp * error;
            return AirflowDemand{std::clamp(p_term + config_.ki * integral_, config_.output_min, config_.output_max)};
        }

        float dt = static_cast<float>(current_time_ms - last_time_ms_) / 1000.0f;
        if (dt <= 0.0f) {
            dt = 0.001f;
        }

        // 1. Proportional term
        float p_term = config_.kp * error;

        // 2. Integral term with anti-windup accumulator clamp
        const float candidate_integral = std::clamp(integral_ + error * dt,
            config_.integral_min, config_.integral_max);
        float i_term = config_.ki * candidate_integral;

        // 3. Filtered derivative term
        float raw_derivative = (error - last_error_) / dt;
        float alpha = config_.derivative_alpha;
        filtered_derivative_ = (alpha * filtered_derivative_) + ((1.0f - alpha) * raw_derivative);
        float d_term = config_.kd * filtered_derivative_;

        // 4. Output with saturation clamp
        float total = p_term + i_term + d_term;
        // Do not integrate further into output saturation; permit unwinding.
        if (!((total > config_.output_max && error > 0.0f) ||
              (total < config_.output_min && error < 0.0f))) {
            integral_ = candidate_integral;
        }
        float output = std::clamp(total, config_.output_min, config_.output_max);

        last_error_ = error;
        last_time_ms_ = current_time_ms;

        return AirflowDemand{output};
    }

private:
    float setpoint_;
    PIDConfig config_;
    float integral_;
    float last_error_;
    uint32_t last_time_ms_;
    float filtered_derivative_;
    bool initialized_;
};

} // namespace SmokerController::Domain

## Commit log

2026-09-20 Enhance README with project details and features
    Expanded project description to include details on temperature sensors and control app.
2026-09-27 feat: initialize PocketSWE framework, 5V fan & servo damper specification, and parametric CAD
    [smoker_damper.scad]
2026-09-27 feat: implement Phase 1 core regulation engine, dual-stage actuator coordinator, and unit tests
2026-09-27 feat: implement Milestone A ESP32 C++ firmware with Onion architecture and LEDC/SPI adapters
2026-09-27 docs: add comprehensive wiring diagram and breadboard guide
2026-09-27 feat(ble): Milestone D - Wireless meat probe integration with composite fallback
2026-09-27 feat(cad): add BBQ Guru Vision Pro S-Series nozzle adapter and slide plate models
    [bbq_guru_vision_pro_nozzle_adapter.stl, damper_rotor.stl, electronics_lid.stl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]
2026-09-28 feat(firmware): configure 4MB partition table, LittleFS filesystem, and pre-flight hardware verification checklist
    [partitions.csv]
2026-09-28 feat(probes): add multi-mode MEATER support (active BLE GATT, Cloud Wi-Fi, passive BLE, wired)
2026-09-28 docs(cad): add 3D printed parts exploded assembly diagram and mechanical assembly guide
2026-09-28 docs(cad): replace assembly diagram with exact 3D render of STL models
2026-09-28 fix(cad): open lateral damper bore and update rotor geometry with assembly diagram
    [damper_rotor.stl, electronics_lid.stl, fan_cover.stl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]
2026-09-28 docs(circuit): add 40x60mm green perfboard circuit board layout and assembly guide
2026-09-28 feat(cad): add Design 2 Roto-Damper RD3 CAD model, STLs, assembly diagram, and docs
    [roto_damper.scad, rotodamper_base.stl, rotodamper_cap.stl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]
2026-10-05 feat(display): add Inland E-Ink screen driver, display view domain, and wiring documentation
2026-10-05 docs: document embedded UI exception and private device access
2026-10-05 Define owned control state, explicit startup, calibration and PID recovery
2026-10-05 Isolate hardware timers, serialize SPI and own control task runtime
2026-10-05 Inhibit initial MAX31855 samples until power-up conversion completes
2026-10-05 Service servo idle deadline on the control task at 20ms cadence
2026-10-05 Adapt domain harness to explicit shared SPI ownership
2026-10-05 Provision private HTTPS access and verify queued calibration controls end to end
2026-10-05 Document protected control API and add repeatable verification driver
2026-10-05 Keep servo settling and thermocouple fault detection within owner-task timing
2026-10-05 Bound HTTPS request lifetime and keep CA signing keys off devices
2026-10-05 Clamp pit faults between PID cycles without advancing healthy control state
2026-10-05 Assert calibrated closure is the very first servo pulse
2026-10-05 Align passive probe harness with explicit scanner ownership
2026-10-05 Refresh BLE discovery and preserve failed HTTPS socket ownership
2026-10-05 Verify HTTPS socket ownership after session-slot reuse
2026-10-05 Repair pinned Arduino BLE service ownership in build-local source
